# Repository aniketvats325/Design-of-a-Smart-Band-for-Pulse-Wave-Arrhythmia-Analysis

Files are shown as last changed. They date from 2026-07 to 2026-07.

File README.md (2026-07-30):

# Design-of-a-Smart-Band-for-Pulse-Wave-Arrhythmia-Analysis
Hardware design of a compact (34 mm × 26 mm) wearable Smart Band optimized for continuous, non-invasive Pulse-Wave Arrhythmia Analysis (PWAA). 
This repository consists following:

- **Board Schematic**: Root Schematic of the Smart Band.
- **PCB Routing**: The connections and pathways for signals and power on the PCB.
- **3D Model**: 3D Model of the design after routing and placement of all components.

- ### Tool Used

The project was developed using an open-source EDA software, **KiCad** version **KiCad 9.0.7**

#### The footprints of all Resistors, Capacitors and Diodes:
`0402_1005Metric_Pad1.08x0.95mm_HandSolder`

## Root Schematic
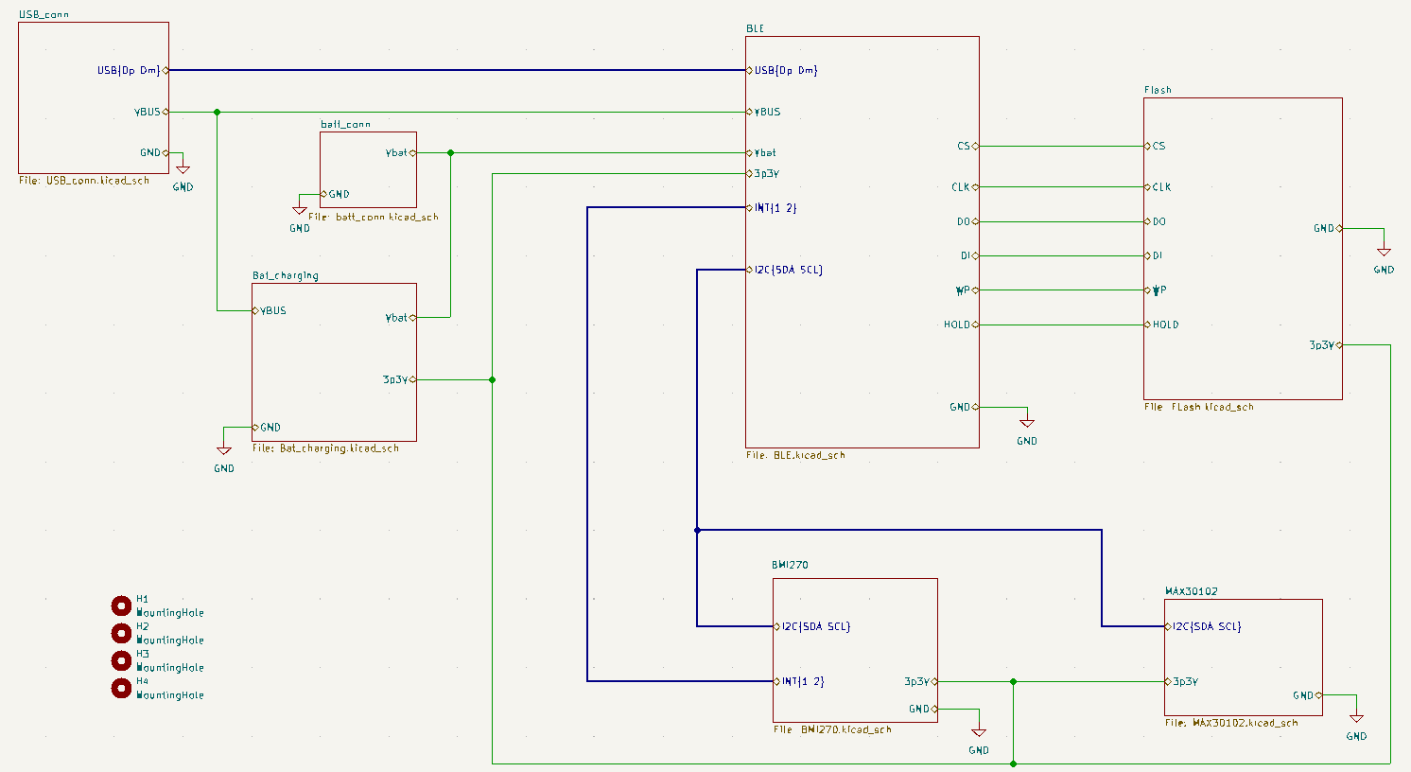
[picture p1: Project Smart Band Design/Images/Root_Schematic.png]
Root Schematic


## PCB Layout with Ground Pouring

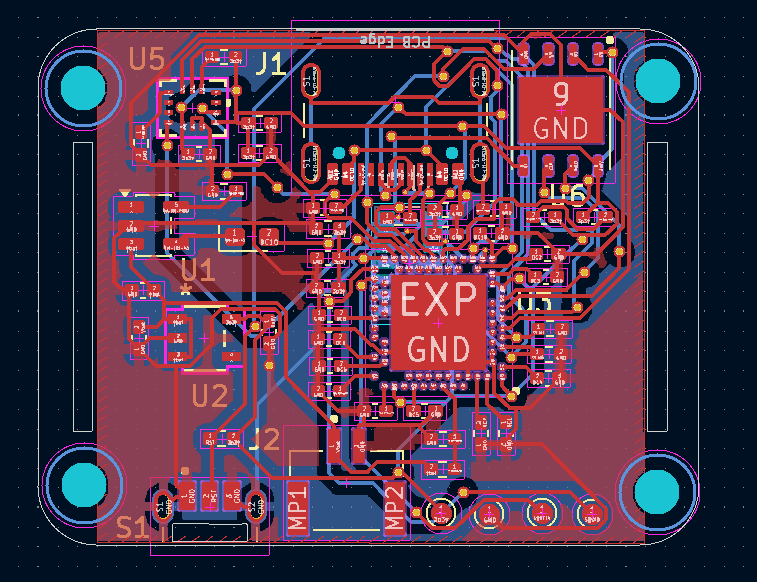
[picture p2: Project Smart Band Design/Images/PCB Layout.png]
PCB Layout with Ground Pouring


## 3D Model Top View

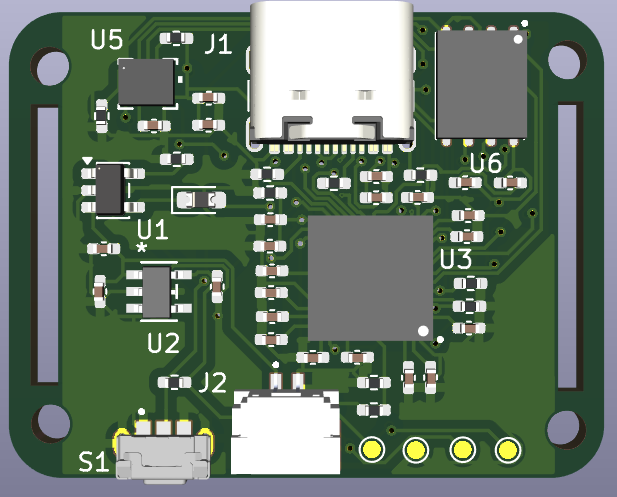
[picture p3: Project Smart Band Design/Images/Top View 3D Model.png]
3D Model Top View


## 3D Model Rear View
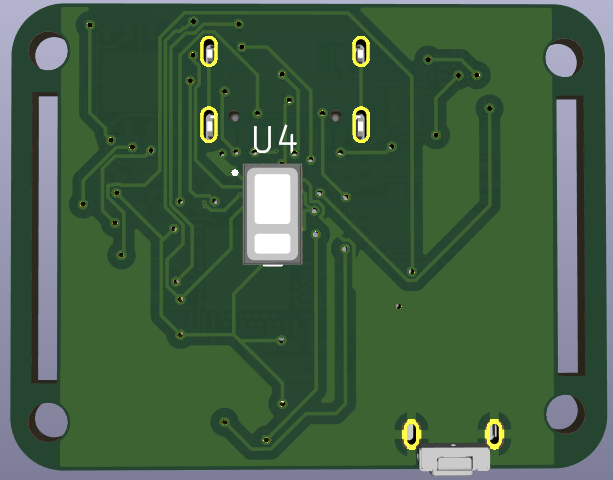
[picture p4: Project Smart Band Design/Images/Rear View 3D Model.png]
3D Model Rear View


## Board Dimensions

| Parameter | Value |
|---|---|
| Width | 36 mm |
| Height | 24 mm |

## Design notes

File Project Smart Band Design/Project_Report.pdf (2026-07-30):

# Survey and Hardware Design of a Smart Wearable System for Pulse Wave Arrhythmia Analysis

Aniket Vats
Department of Electronics and Communication Engineering International Institute of Information Technology Bangalore Bengaluru, India
Aniket.Vats@iiitb.ac.in

Abstract—This paper presents a survey and complete endto-end hardware design of a compact (34 mm × 26 mm) wearable Smart Band optimized for continuous, non-invasive Pulse-Wave Arrhythmia Analysis (PWAA). The system leverages Photoplethysmography (PPG) using a high-sensitivity integrated optical sensor (MAX30102) combined with a low-power 6-axis Inertial Measurement Unit (BMI270) for adaptive motion artifact cancellation. Processing and wireless transmission are managed by the Nordic nRF52840 Bluetooth Low Energy (BLE) System-on-Chip (SoC) supported by 32 Mb external NOR Flash (W25Q32JV) for local data logging. The document outlines the continuous arrhythmia monitoring pipeline, classifies commercial devices across different product categories, and details the complete KiCad schematic, component selection, printed circuit board (PCB) floorplanning, routing, and Bill of Materials.

GitHub Repository: Smart-Band-Design (https://github.com/aniketvats325/Design-of-a-Smart-Band-for-Pulse-Wave-Arrhythmia-Analysis)

Index Terms—Photoplethysmography (PPG), Pulse-Wave Arrhythmia Analysis (PWAA), KiCad PCB Design

I. INTRODUCTION

Cardiovascular diseases are among the leading causes of death worldwide. Many heart-related disorders, such as arrhythmias, may occur without noticeable symptoms during their early stages. Continuous monitoring of heart activity can help in the early detection of such conditions and improve timely medical intervention. With recent advancements in wearable technology, smart wearable devices have become an effective solution for continuous health monitoring due to their compact size, low power consumption, and ease of use.
One of the most widely used techniques in wearable health monitoring is Photoplethysmography (PPG). PPG is a non-invasive optical method that measures changes in blood volume by illuminating the skin with light and detecting the reflected light using a photodetector. The acquired pulse wave contains valuable information about heart rate, heart rate variability, blood oxygen saturation, and pulse rhythm. By analyzing the pulse wave, irregular heart rhythms (arrhythmias) can be identified, making PPG-based devices suitable for continuous cardiac monitoring.
Several commercial wearable devices, such as WHOOP, Fitbit, Apple Watch and Samsung Galaxy Watch, use PPG sensors along with motion sensors to provide continuous health tracking. These devices integrate low-power microcontrollers, optical sensors, inertial measurement units (IMUs), wireless communication, and rechargeable batteries into compact wearable designs. Studying these devices helps in understanding current design practices and selecting suitable components for developing a custom wearable system.
In this project, a survey of commercially available wearable devices and relevant literature was first conducted to understand the principles of pulse wave arrhythmia analysis and the hardware architecture used in modern wearables. Based on this study, a compact smart wearable band was designed for pulse wave arrhythmia analysis.

II. PULSE-WAVE ARRHYTHMIA ANALYSIS PROCESS

A. Optical Sensing Principles

PPG is a non-invasive optical technique used to measure changes in blood volume in the arteries. It works by illuminating the skin with light from an LED and measuring the reflected light using a photo detector. During systole, the blood volume increases, resulting in higher light absorption and lower reflected light. During diastole, the blood volume decreases, leading to lower absorption and higher reflected light. These periodic changes form the PPG signal, which is used to measure heart rate and detect pulse wave irregularities. Green light (520–530 nm) is primarily used for heart rate and pulse wave arrhythmia analysis because it provides a strong signal from blood near the skin surface. Red (660 nm) and infrared (880–940 nm) light penetrate deeper into the tissue and are mainly used for blood oxygen saturation (SpO2) measurement.
The PPG signal consists of two components: the DC component (95–99)%, which represents the constant absorption by tissues, bones, and non-pulsatile blood, and the AC component (1–5)%, which corresponds to the pulsatile arterial blood flow generated by each heartbeat. Since the AC component is very small, extracting it accurately is a key challenge in PPG signal processing.
To reduce power consumption, the LEDs are driven using short pulses instead of continuous illumination. During the LED-off period, the sensor measures ambient light, which is then subtracted from the measured signal to improve accuracy and reduce the effects of external lighting.

B. Analog Front End Architecture
The electrical signal produced by the photodiode is extremely weak, typically in the picoampere to nanoampere range, and cannot be processed directly by a microcontroller. Therefore, an Analog Front End is used to condition and amplify the signal. First, a Transimpedance Amplifier converts the small photodiode current into a measurable voltage. Next, the DC cancellation circuit removes the large DC component caused by tissues and non-pulsatile blood, preventing the amplifier from saturating and allowing the small pulsatile signal to be extracted. The remaining AC component is then amplified by a Programmable Gain Amplifier to make full use of the input range of the ADC. Finally, the ADC converts the conditioned analog signal into a high-resolution digital signal, typically with 18–20 bit resolution and sampling rates between 50 Hz and 400 Hz. The digitized PPG signal is then processed by the microcontroller for heart rate measurement and pulse wave arrhythmia analysis.
C. Digital Filtering and Motion Artifact Rejection
The raw PPG signal obtained from the optical sensor is often affected by various sources of noise, including electronic interference, ambient light, and motion artifacts caused by wrist movements. These unwanted signals can distort the PPG waveform and reduce the accuracy of heart rate and arrhythmia detection. To improve signal quality, the acquired PPG signal is first passed through a bandpass filter with a frequency range of approximately 0.5 Hz to 5 Hz, which corresponds to the normal range of human heart rates. This filter suppresses low-frequency baseline drift and high-frequency noise while preserving the useful cardiac information.
Motion artifacts are one of the most significant challenges in wearable PPG systems. During hand or wrist movements, the deformation of skin and underlying tissues changes the optical path between the LED and the photodiode, producing fluctuations that can closely resemble genuine heartbeat signals. To distinguish these false signals from actual pulse waves, an accelerometer continuously measures the movement of the wrist. The motion data is then used by signal processing algorithms to identify and estimate the motion-induced noise. An Adaptive Least Mean Squares (LMS) filter models the motion artifacts using the accelerometer data as a reference and continuously subtracts the estimated noise from the PPG signal. This adaptive filtering process significantly improves the quality of the PPG signal, enabling more accurate heart rate measurement and pulse wave arrhythmia analysis even during moderate body movements.

TABLE I
ECG VS PPG
ECG | PPG
Measures electrical activity | Measures blood volume changes
Requires Electrodes | Require LEDs and Photodiodes
Higher Diagnostic accuracyr | Good for continuous screening
More expensive | Lower Cost
Clinical Equipments | Wearables
D. Feature Extraction

The next step is to identify the systolic peak in each cardiac cycle of the PPG signal. The systolic peak corresponds to the maximum blood volume in the arteries during heart contraction and is used to calculate important cardiovascular parameters. Peak detection is commonly performed using a threshold-and-slope algorithm, in which the signal must exceed an adaptive threshold and simultaneously be a local maximum. To prevent the same heartbeat from being detected multiple times, a refractory period of at least 300 ms is maintained between successive peaks. Once the systolic peaks are detected, the Inter-Beat Interval (IBI) is calculated as the time difference between two consecutive peaks. The IBI is then used to determine heart rate, heart rate variability, and detect irregular pulse rhythms associated with arrhythmias. The processed data is managed by the SoC, which controls sensor operation, performs signal processing, manages power consumption, and transmits the measured data wirelessly to a smartphone or other external device using BLE. This integrated approach enables continuous, real-time monitoring while maintaining low power consumption, making it suitable for wearable health monitoring applications.

III. SURVEY OF COMMERCIAL DEVICES UTILIZING PWAA

A. Smartwatches

Smartwatches are the most popular category of wearable health monitoring devices. They combine powerful processors, wireless connectivity, optical sensors, and advanced software to provide continuous monitoring of cardiovascular health, physical activity, and sleep.
- Apple Watch Series 9 / Ultra 2: Uses multiple green, red, and infrared LEDs with photodiodes for continuous PPG monitoring. It detects irregular heart rhythms and supports on-demand single-lead ECG recording for atrial fibrillation (AFib) detection.
- Samsung Galaxy Watch 7 / Ultra: Features Samsung’s BioActive sensor, which integrates PPG, ECG, and Bioelectrical Impedance Analysis (BIA). It provides continuous heart rate monitoring, AFib detection, blood oxygen measurement, sleep tracking, and body composition analysis.
- Google Pixel Watch 3 / 4: Combines Fitbit’s health monitoring algorithms with multi-path PPG sensors to provide continuous heart rate monitoring, sleep analysis, and AFib detection.
- Garmin Venu 4 / Fenix 8: Equipped with Garmin Elevate optical heart rate sensors for continuous heart rate monitoring, Pulse Ox (SpO2), stress monitoring, sleep analysis, and heart rate variability (HRV). These watches are optimized for fitness, outdoor activities, and long battery life while supporting advanced physiological monitoring.
- Amazfit Balance and Huawei Watch GT4: Utilize multi-channel optical PPG sensors for continuous heart rate, blood oxygen, stress, and sleep monitoring while maintaining extended battery life.
B. Smart Bands

Screenless smart bands are designed for continuous physiological monitoring without a display. Eliminating the display reduces power consumption, decreases weight, and enables multi-day battery life, making them suitable for 24/7 health monitoring.
- WHOOP MG (Medical Grade): A medical-grade wearable focused on continuous cardiovascular monitoring, recovery analysis, and strain measurement. It employs multiple green, red, and infrared LEDs with multiple photodiodes to acquire high-quality PPG signals and stores data locally before synchronizing with a smartphone via Bluetooth Low Energy (BLE).
- WHOOP 4.0 / 5.0: Designed for continuous heart rate, recovery, sleep, and activity monitoring using multiwavelength PPG sensors and onboard memory for uninterrupted data logging.
- Hume Band 2.0: A lightweight screenless wearable that continuously monitors heart rate, heart rate variability, stress, recovery, sleep quality, and daily activity while providing long battery life.
- Huawei Band 9 / Honor Band 10: Affordable fitness bands equipped with optical PPG sensors for continuous heart rate, SpO2, sleep, and stress monitoring. They offer slim designs, long battery life, and comprehensive health tracking features.
C. Hybrid Smartwatches

Hybrid smartwatches combine the appearance of traditional analog watches with modern health monitoring capabilities. Hidden displays and optical sensors provide continuous health tracking while maintaining long battery life.
- Withings ScanWatch 2, Nova, and Nova Brilliant: Provide continuous heart rate monitoring using multiwavelength PPG sensors, on-demand ECG recording, blood oxygen measurement, and up to 30 days of battery life.
D. Smart Rings

Smart rings provide continuous physiological monitoring in a compact and lightweight form factor. Since fingers contain dense capillary networks, they offer excellent PPG signal quality for cardiovascular monitoring.
- Oura Ring Gen 4 and Samsung Galaxy Ring: Integrate green, red, and infrared LEDs, temperature sensors, and motion sensors for monitoring heart rate, sleep, blood oxygen saturation, body temperature, and activity.
- CART-I Ring (Sky Labs): A medical-grade smart ring designed specifically for continuous atrial fibrillation (AFib) monitoring and remote patient care.
E. Medical Patches
Medical patches prioritize diagnostic accuracy over portability and are widely used for long-term clinical ECG monitoring.
- iRhythm Zio XT: A waterproof adhesive chest patch capable of recording continuous single-lead ECG signals for up to 14 days. The recorded data is analyzed using AI-based algorithms for arrhythmia detection.
- AliveCor KardiaMobile 6L and Spyder Patch: Portable ECG devices that provide real-time wireless arrhythmia monitoring through smartphone applications.
F. Smart Textiles
Smart textiles integrate conductive electrodes into garments, enabling comfortable and continuous physiological monitoring during daily activities and sports.
- Hexoskin Medical System, BioSerenity Cardioskin, and Nuubo nECG Holter: These smart garments provide continuous ECG monitoring, respiration analysis, activity tracking, and long-duration physiological monitoring for clinical and sports applications.

IV. SMART BAND KICAD DESIGN
To demonstrate the practical realization of a compact PWAA monitor, a custom PCB was designed in KiCad. The board measures 34 mm × 26 mm with side strap cutouts, adopting the screenless Whoop 4.0 form factor.
A. Root Schematic Architecture
The proposed smart wearable band is designed using a modular hierarchical architecture in KiCad, where each functional block is implemented as a separate schematic sheet and integrated into the root schematic. The system is powered through a USB Type-C interface, which provides a 5 V input supply for battery charging and supports USB communication with the microcontroller. The USB Type-C connector uses 5.1 kΩ pulldown resistors on the CC1 and CC2 pins for device detection, while the D+ and D- lines are connected directly to the microcontroller for programming and debugging. A Microchip MCP73831 linear battery charger is employed to charge a single-cell Li-ion battery using the constant-current/constantvoltage charging method, with the charging current set to approximately 500 mA using a 2 kΩ programming resistor. The rechargeable 150 mAh Li-Po battery can be connected through a compact JST GHS two-pin connector, making the design suitable for wearable applications.
The battery voltage, which varies between 3V and 4.2V, is regulated to a stable 3.3 V using the TPS7A0233 low-dropout voltage regulator. This regulated supply powers all digital and sensing components while maintaining extremely low quiescent current, thereby extending battery life. The central processing unit of the system is the Nordic nRF52840-QIAA-R System-on-Chip, which integrates a 32-bit ARM Cortex-M4 processor operating at 64 MHz along with Bluetooth Low Energy (BLE) connectivity. The microcontroller is responsible for sensor interfacing, signal processing, power management, local data handling, and wireless communication with external devices. To enable offline storage of physiological data, a W25Q32JV 32 Mbit Serial NOR Flash memory is connected through the SPI interface, allowing sensor data to be stored when a Bluetooth connection is unavailable.
Physiological signals are acquired using the MAX30102 optical PPG sensor, which integrates red and infrared LEDs, a photodetector, an analog front end, and an 18-bit analogto-digital converter within a single package. The sensor communicates with the microcontroller through the I²C interface and uses an interrupt pin to indicate the availability of new measurement data. To improve measurement accuracy during body movement, the design also includes the Bosch BMI270 six-axis inertial measurement unit, which provides three-axis accelerometer and three-axis gyroscope data. The motion information obtained from the IMU is used for motion artifact reduction, thereby improving the reliability of pulse wave analysis. The combination of low-power components, efficient power management, wireless connectivity, and compact PCB design makes the proposed hardware architecture well suited for continuous pulse wave arrhythmia monitoring in a wearable smartband.
B. PCB Layout and Physical Floorplanning
The component placement follows a functional floorplanning approach to minimize routing complexity and optimize system performance. The Nordic nRF52840 SoC is positioned near the center of the top layer to reduce trace lengths to peripheral devices. The USB Type-C connector is placed along the top edge of the board for convenient charging and programming access, while the W25Q32JV external flash memory and BMI270 motion sensor are positioned close to the microcontroller to simplify high-speed SPI and I²C routing. The battery charging circuit, consisting of the MCP73831 charger and TPS7A0233 LDO regulator, is located together to provide a compact power management section. The JST battery connector and reset push button are placed near the bottom edge for easy battery connection and system reset. Four plated mounting holes are provided at the corners of the PCB to securely fasten the board within the enclosure.
The bottom layer is reserved exclusively for the MAX30102 optical PPG sensor, which is positioned at the geometric center of the PCB. This placement ensures direct and uniform contact between the sensor and the user’s wrist when the device is worn, thereby improving the quality of the acquired photoplethysmography signals. The PCB outline incorporates rounded corners with a 2 mm radius to improve user comfort and reduce sharp edges. In addition, two rectangular slots are provided along the left and right edges of the board, allowing a fabric wrist strap to pass directly through the PCB. This mechanical arrangement provides a secure attachment mechanism while maintaining a slim and lightweight wearable design.
V. RESULTS

The completed PCB design was successfully verified using the KiCad Design Rule Check (DRC) tool. The verification


Fig. 1. Root Schematic

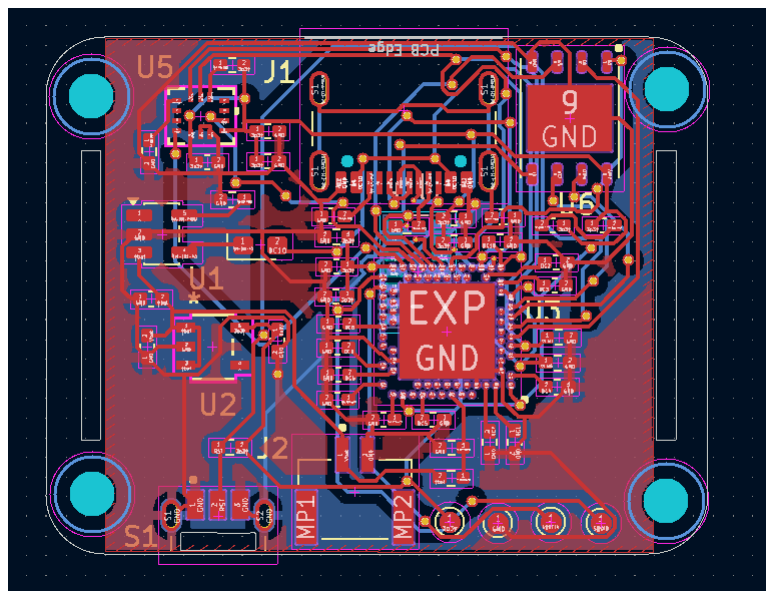
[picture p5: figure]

Fig. 2. PCB Layout

confirmed zero design rule violations and zero unrouted nets, indicating that all electrical connections were correctly routed and the PCB satisfies the specified design constraints.
After successful verification, all manufacturing files required for PCB fabrication and assembly were generated. The Gerber fabrication files include the copper layers, solder mask layers, silkscreen layers, and board Edge Cuts, which are used by PCB manufacturers to produce the printed circuit board. n addition, a Bill of Materials (BOM) file was generated, listing all components along with their manufacturer part numbers and quantities required for assembling the smart wearable band.

VI. CONCLUSION

The estimated hardware cost of the proposed smartband is approximately Rs.4,000, including the major electronic components, passive components, PCB fabrication, connectors, and battery. Although this cost is comparable to the manufacturing cost of several commercial wearables, it is significantly lower than the retail prices of premium products such as Whoop, Oura Ring, and high-end smartwatches. Commercial wearable devices are priced much higher because


Fig. 3. 3D Model Top View


Fig. 4. 3D Model Rear View

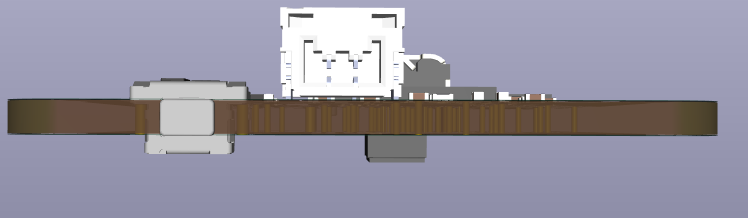
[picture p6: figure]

Fig. 5. Side view showing Reset Button

TABLE II
MAJOR COMPONENTS USED IN THE SMART BAND
Component | Part Number | Approx. Price (INR)
Nordic BLE SoC | nRF52840-QIAA-R7 | 734
Optical PPG Sensor | MAX30102EFD+T | 1306
6-Axis IMU | BMI270 | 404
Serial NOR Flash | W25Q32JVZPIQ | 224
Li-Ion Battery Charger | MCP73831-2-OT | 73
3.3 V LDO Regulator | TPS7A0233DBVR | 81
USB Type-C Receptacle | TYPE-C-31-M-12 | 250
Battery Connector | SM02B-GHS-TB | 34

the final product cost includes research and development, proprietary algorithms, custom mechanical enclosure design, mobile application development, cloud infrastructure, certifications, quality assurance, marketing, distribution, customer support, and company profit margins. In contrast, the proposed design focuses solely on the essential hardware required for pulse-wave arrhythmia monitoring, resulting in a much more economical solution while maintaining the core sensing and wireless communication capabilities.
This smartband can be further enhanced by implementing embedded firmware for real-time PPG signal acquisition, digital filtering, systolic peak detection, and arrhythmia classification. A dedicated mobile application can be developed to display live physiological data, maintain health records, and generate alerts for abnormal heart rhythms. The hardware can also be expanded by integrating additional sensors such as an ECG front-end, skin temperature sensor, galvanic skin response (GSR) sensor, or blood pressure estimation algorithms to provide comprehensive health monitoring. Incorporating machine learning models for automatic arrhythmia detection and personalized health analysis can further improve diagnostic accuracy. Future versions may also include wireless charging, a flexible PCB, waterproof enclosure, improved power management for longer battery life, and cloud-based data synchronization for remote patient monitoring and telemedicine applications.

REFERENCES

[1] J. Allen, “Photoplethysmography and its application in clinical physiological measurement,” Physiological Measurement, vol. 28, no. 3, pp. R1–R39, Mar. 2007.
[2] J. Y. A. Foo and S. J. Wilson, “A computational system to optimise noise removal in photoplethysmography signals,” Medical Biological Engineering Computing, vol. 44, no. 3, pp. 216–224, 2006.
[3] Analog Devices, MAX30102 High-Sensitivity Pulse Oximeter and Heart-Rate Sensor for Wearable Health, Rev. 1, 2018.
[4] Nordic Semiconductor, nRF52840 Product Specification v1.9, Trondheim, Norway.
[5] Bosch Sensortec GmbH, BMI270 Ultra-Low Power Smart IMU Datasheet, Rev. 2.6, 2022.
[6] Winbond Electronics Corp., W25Q32JV 32-Mbit Serial Flash Memory Datasheet, Rev. I.
[7] Microchip Technology Inc., MCP73831/2 Stand-Alone Linear Li-Ion/Li-Polymer Charge Management Controller Datasheet, DS20001984.
[8] Texas Instruments, TPS7A02 200-mA, Ultra-Low-IQ Low-Dropout Voltage Regulator Datasheet, Rev. G.
[9] KiCad Developers, KiCad EDA – Electronic Design Automation Suite, Version 9.0, 2025. Available: https://www.kicad.org/

[10] A. M. Chan, N. Ferdosi, and R. Narasimhan, “Ambulatory electrocardiogram monitoring devices for evaluating transient loss of consciousness or other related symptoms,” Journal of Arrhythmia, vol. 36, no. 1, pp. 12–26, 2020.
[11] H. M. Charlton et al., “Wearable photoplethysmography for cardiovascular monitoring,” Proceedings of the IEEE, vol. 110, no. 3, pp. 355–381, 2022.
[12] Apple Inc., “ECG app and irregular heart rhythm notification available on Apple Watch,” Apple Newsroom, Sep. 19, 2019. [Online].
[13] Samsung Electronics Co., Ltd., Samsung Health Monitor – ECG, Blood Pressure and Irregular Heart Rhythm Notification, Samsung. [Online].
[14] Huawei Technologies Co., Ltd., Pulse Wave Arrhythmia Analysis on Your HUAWEI Watch/Band, Huawei Support. [Online].
[15] WHOOP Inc., WHOOP Health & Performance Wearable, Boston, MA, USA. [Online].
[16] S. Saganowski et al., “Consumer Wearables and Affective Computing for Wellbeing Support,” arXiv preprint arXiv:2005.00093, 2020.

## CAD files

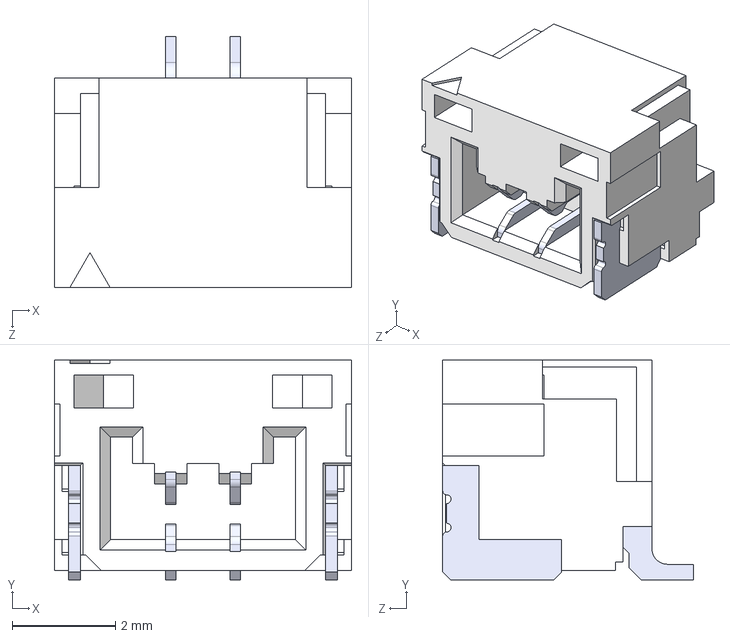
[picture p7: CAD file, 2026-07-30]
Project Smart Band Design/3D Models/SM02B-GHS-TB.step
5.75 x 4.25 x 4.85 mm
SMxB-GHS-TB_02
pin x 2

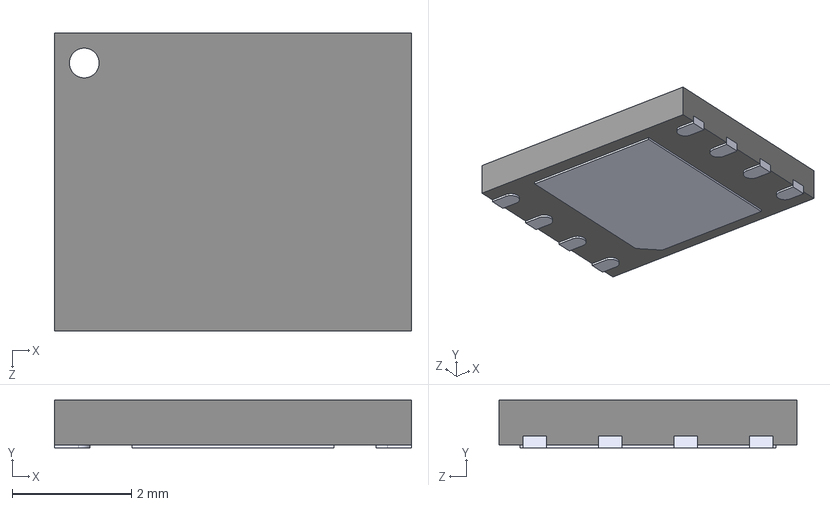
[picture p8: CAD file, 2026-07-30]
Project Smart Band Design/3D Models/W25Q32JVZPIQ.step
6.00 x 0.8 x 5.00 mm

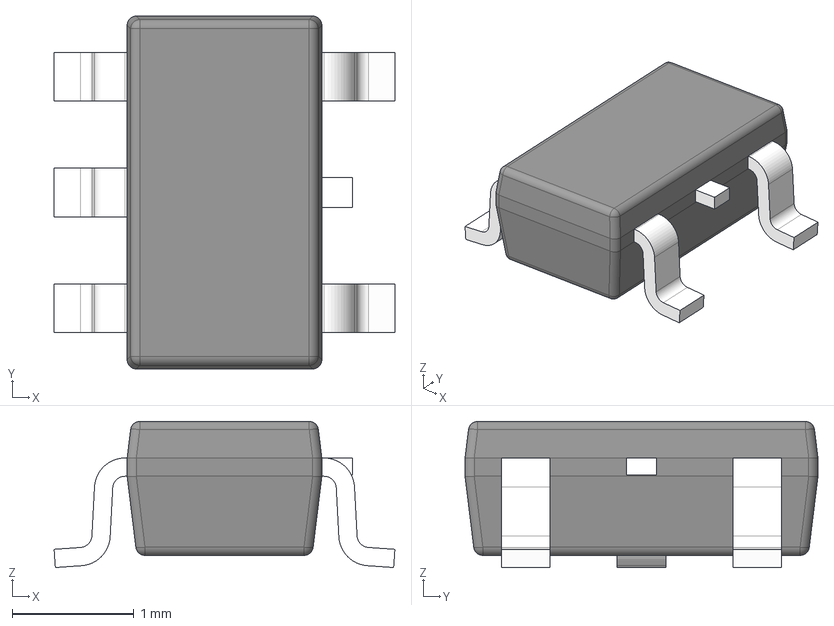
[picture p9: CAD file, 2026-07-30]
Project Smart Band Design/3D Models/DBV0005A.stp
2.80 x 2.90 x 1.20 mm
BODY-SOT
LEAD-SOT x 5
LEAD-DUMMY

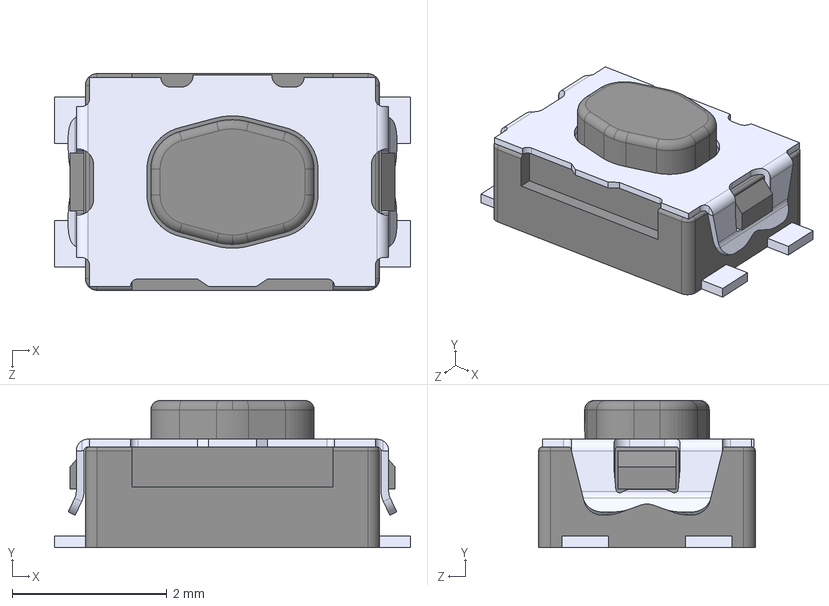
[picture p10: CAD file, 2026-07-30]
Project Smart Band Design/3D Models/KMR621NGLFS.step
4.60 x 1.90 x 2.80 mm

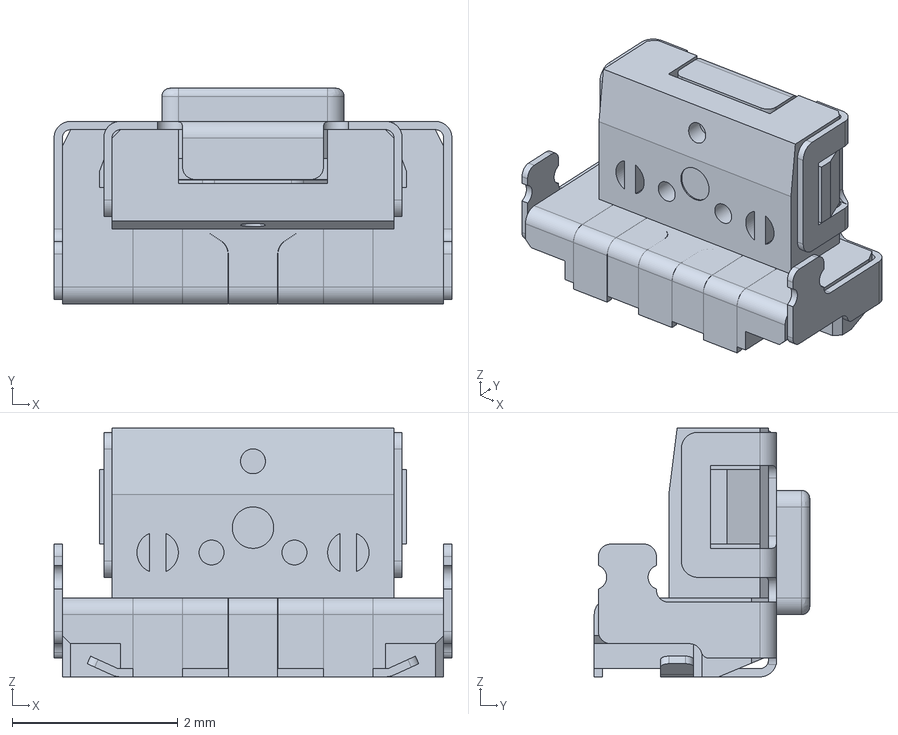
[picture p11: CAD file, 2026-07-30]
Project Smart Band Design/3D Models/PTS847MM160LSMTR2 LFS.stp
4.80 x 2.60 x 3.00 mm

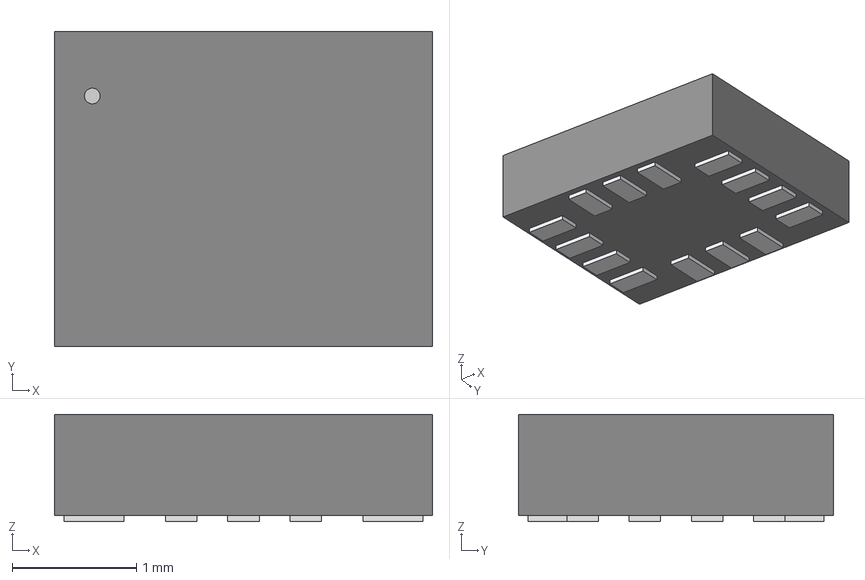
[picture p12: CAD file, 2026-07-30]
Project Smart Band Design/3D Models/BMI270_BOS.step
3.05 x 2.54 x 0.866 mm

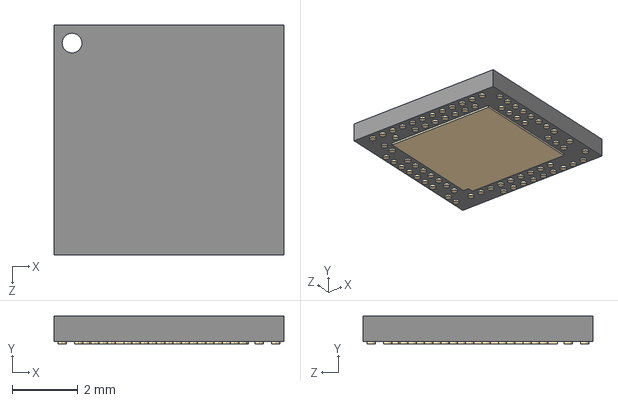
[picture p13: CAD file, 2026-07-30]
Project Smart Band Design/3D Models/NRF52840-QIAA-R7.step
7.00 x 0.85 x 7.00 mm

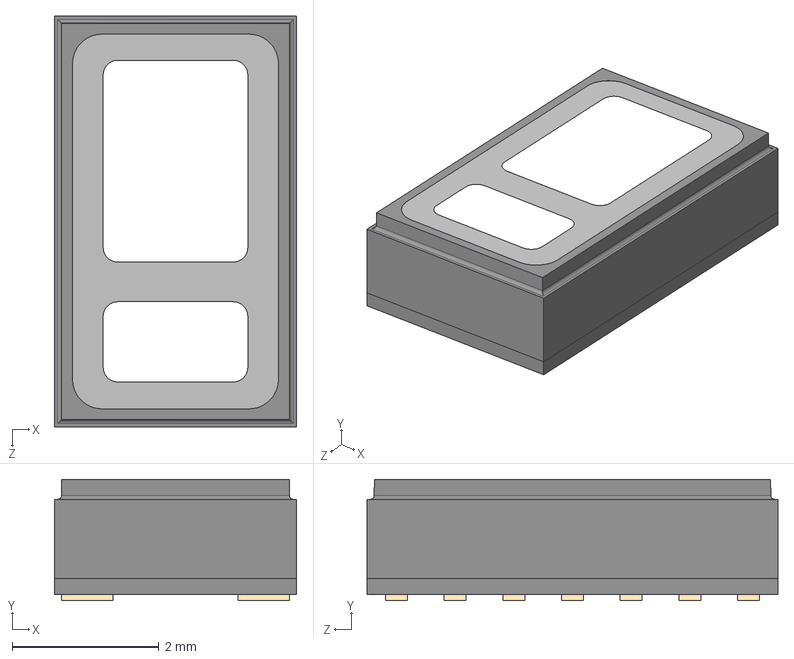
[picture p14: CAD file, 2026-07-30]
Project Smart Band Design/3D Models/MAX30102EFD_T.step
3.30 x 1.65 x 5.60 mm

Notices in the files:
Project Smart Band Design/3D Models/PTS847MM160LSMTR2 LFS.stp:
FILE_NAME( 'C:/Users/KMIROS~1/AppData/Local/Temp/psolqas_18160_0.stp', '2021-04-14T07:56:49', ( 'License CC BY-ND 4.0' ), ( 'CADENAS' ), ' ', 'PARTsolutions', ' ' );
